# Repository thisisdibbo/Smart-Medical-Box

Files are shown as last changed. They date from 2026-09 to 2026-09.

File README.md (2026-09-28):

<p align="center">
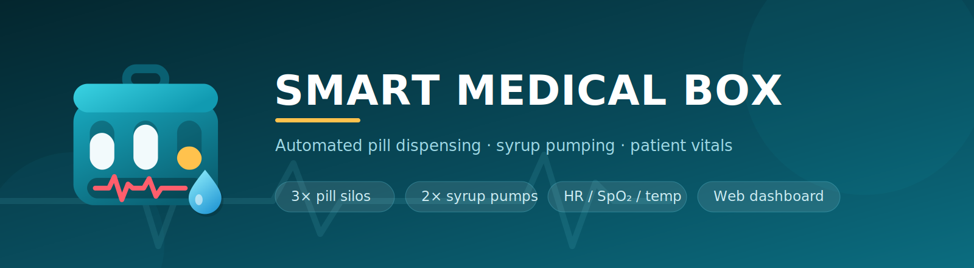
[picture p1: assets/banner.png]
Smart Medical Box
  
</p>

<p align="center">
  
  
  
  
  
</p>

A desk-sized medicine cabinet that dispenses the right pills at the right time, pumps a
measured dose of syrup after them, and reads the patient's vitals while it does it.

Three motorised silos drop one tablet each into a shared tray. A piezo disc under the tray
listens for the drop, so the box counts pills it has actually delivered rather than pills it
*thinks* it delivered. Two peristaltic pumps then run for a configurable duration. Everything
is driven by a schedule you set from a browser — morning, day and night can each have their
own silo order, pump order and dose length.

A second ESP32 handles the patient side: heart rate, SpO₂, body temperature and the water
tank level, shown live on a 3.5" TFT and pushed over Wi-Fi to the main controller so the web
dashboard sees them too.

---

## The build

| Assembled | Inside | On the bench |
|:--:|:--:|:--:|
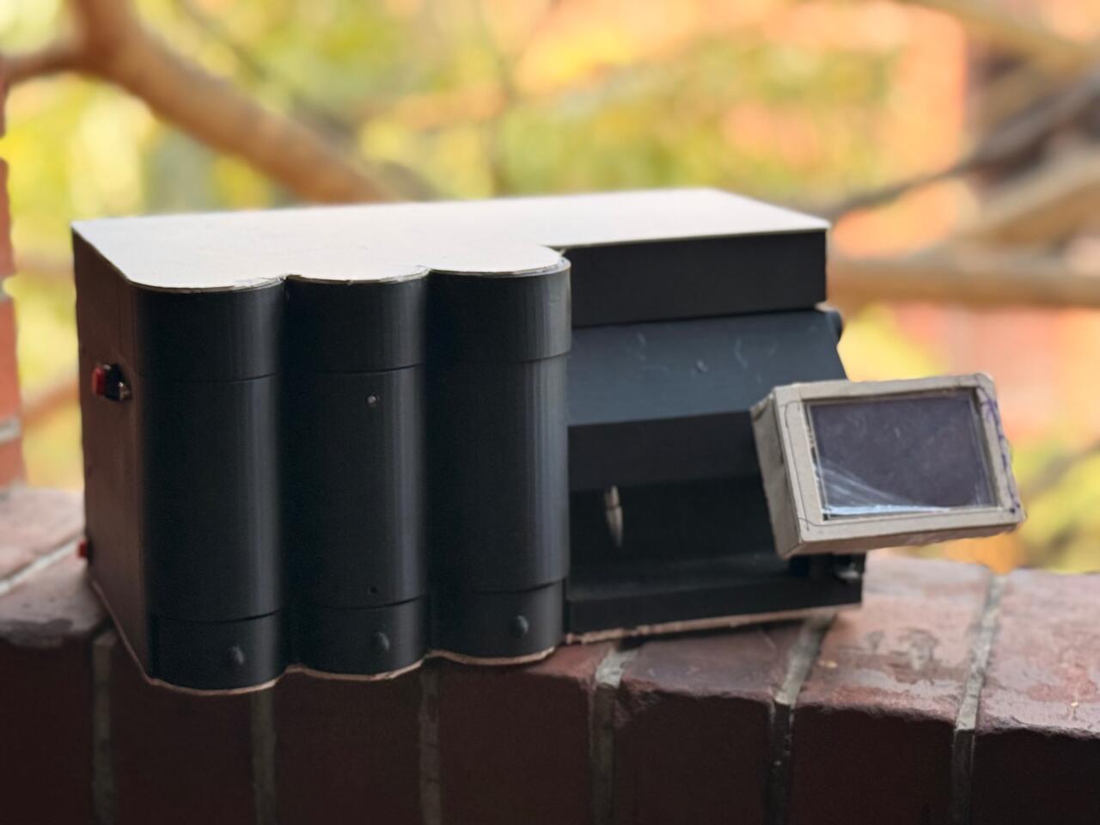
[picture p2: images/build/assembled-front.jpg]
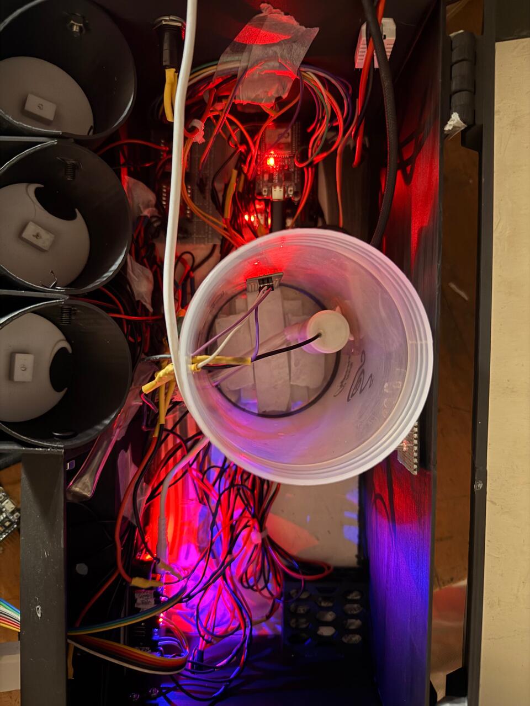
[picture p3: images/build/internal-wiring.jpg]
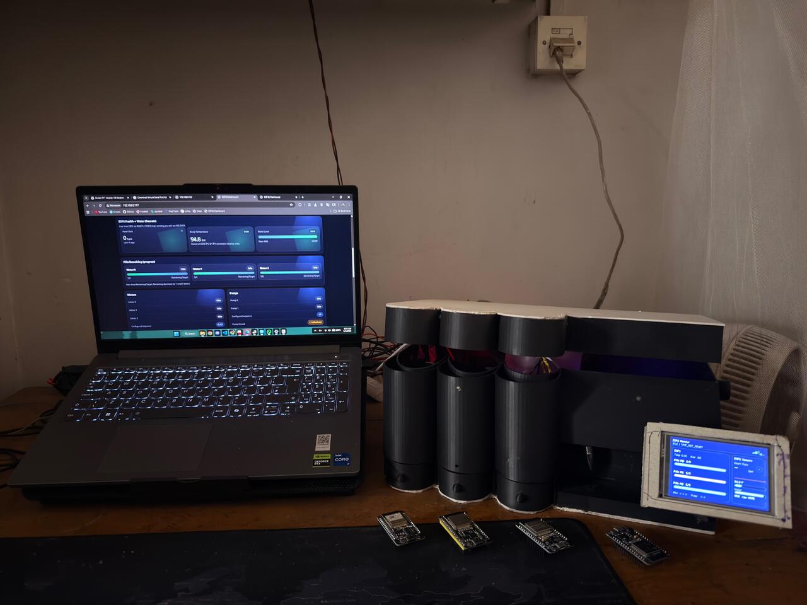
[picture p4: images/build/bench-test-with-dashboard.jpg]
|  |  |  |
| Three pill silos, hinged lid, TFT on a swing-out arm | Silos, water reservoir, drivers and the UV strip | Dashboard in the browser, TFT mirroring it |

### The dashboard

Served straight from the controller's flash — one HTML page, no app, no cloud, no account.
Open the box's address on any device on the same network.

<p align="center">
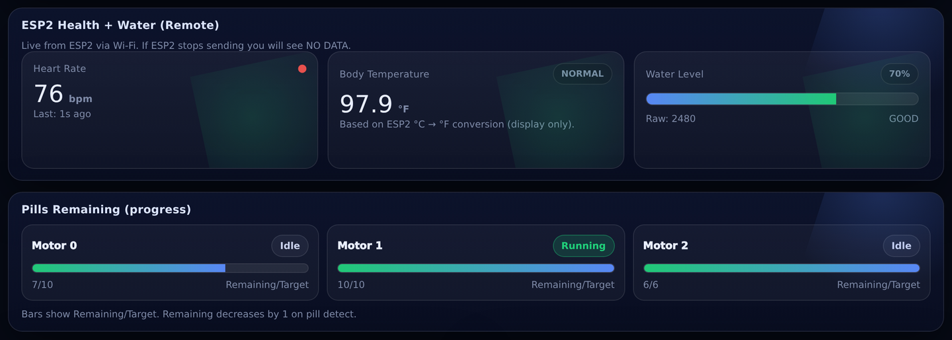
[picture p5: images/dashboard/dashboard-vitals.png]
Live vitals and pill counters
  
</p>

---

## What it does

**Dispensing**

- 3 independent pill silos, each on its own gear motor and rotating disc
- One pill per rotation; the disc pocket only ever holds a single tablet
- Piezo-disc drop detection — the motor stops the moment a pill is heard, not after a fixed time
- Per-silo pill counters that survive a power cut (stored in NVS)
- The sequence skips any silo whose counter has reached zero

**Liquid**

- 2 pumps, each with short / medium / long dose presets (1.0–5.0 s)
- Pumps run only after every scheduled silo has delivered
- Analog water-level probe with a smoothed percentage readout

**Patient monitoring**

- MAX30102 for heart rate and SpO₂, with finger-presence detection so it doesn't report noise
- I²C body-temperature sensor, clamped to a plausible 34–41 °C window
- DHT22 for cabinet temperature and humidity
- Live 3.5" TFT panel with a pulse waveform, thermometer bar and tank gauge

**Control**

- Built-in web dashboard on the controller — no app, no cloud, no account
- Three schedule windows (morning / day / night), each with its own silo and pump programme
- NTP clock so the windows follow real local time
- Physical start button, plus a latching emergency switch that cuts every output and sirens
- Four status LEDs: sequence started, sequence done, pump started, pump done

---

## How it works

The controller runs a four-state machine. One press of the start button (or `GET /startSequence`)
walks it all the way through:

```
        ┌──────┐   button / web    ┌────────────┐
        │ IDLE │ ────────────────► │ RUN_MOTOR  │ ◄──────────────┐
        └──────┘                   └─────┬──────┘                │
            ▲                            │ piezo > 400           │ next silo
            │                            ▼                       │ in the sequence
            │                    ┌─────────────────┐             │
            │                    │ WAIT_AFTER_PILL │ ────────────┘
            │                    └────────┬────────┘
            │                             │ all silos done
            │                             ▼
            │   last pump finished  ┌──────────┐
            └────────────────────── │ RUN_PUMP │
                                    └──────────┘
```

At the moment the button is pressed the firmware looks at the clock, picks whichever schedule
window is active, and copies that window's silo order, pump order and dose lengths into the
runtime. If no window is active it falls back to the saved defaults. That is why the same
button gives you two tablets in the morning and one at night without you touching anything.

The emergency switch is checked on every loop iteration, ahead of the state machine — it drops
the state back to `IDLE`, kills all motors and pumps, and toggles the buzzer every 200 ms for
as long as it is held.

---

## System architecture

The two boards are **not** wired to each other. They talk over Wi-Fi on the local network:

```
   ESP32 #2  (sensors + TFT)                    ESP32 #1  (controller)
   ─────────────────────────                    ─────────────────────
   MAX30102   ──┐                               3 × gear motor + driver
   Temp 0x7F  ──┼─ I²C                          2 × pump relay
   Water probe ─┘                               Piezo disc, DHT22
        │                                       Button, emergency, buzzer, LEDs
        │  GET /ingest?bpm=&body=&water=   ───►         │
        │           every 1.5 s                         │
        │                                               ▼
        │  GET /status  ◄───────────────────────  WebServer :80
        │           every 1 s, JSON                  + NVS + NTP
        ▼                                               │
   3.5" TFT 480×320                                     ▼
                                                  Browser dashboard
```

ESP32 #2 pushes its readings to `/ingest` and polls `/status` for everything the controller
knows, so the TFT and the browser always show the same numbers. If the controller drops off the
network, the TFT falls back to showing `ESP1 OFFLINE` and keeps displaying its own local sensors.

---

## Circuit

<p align="center">
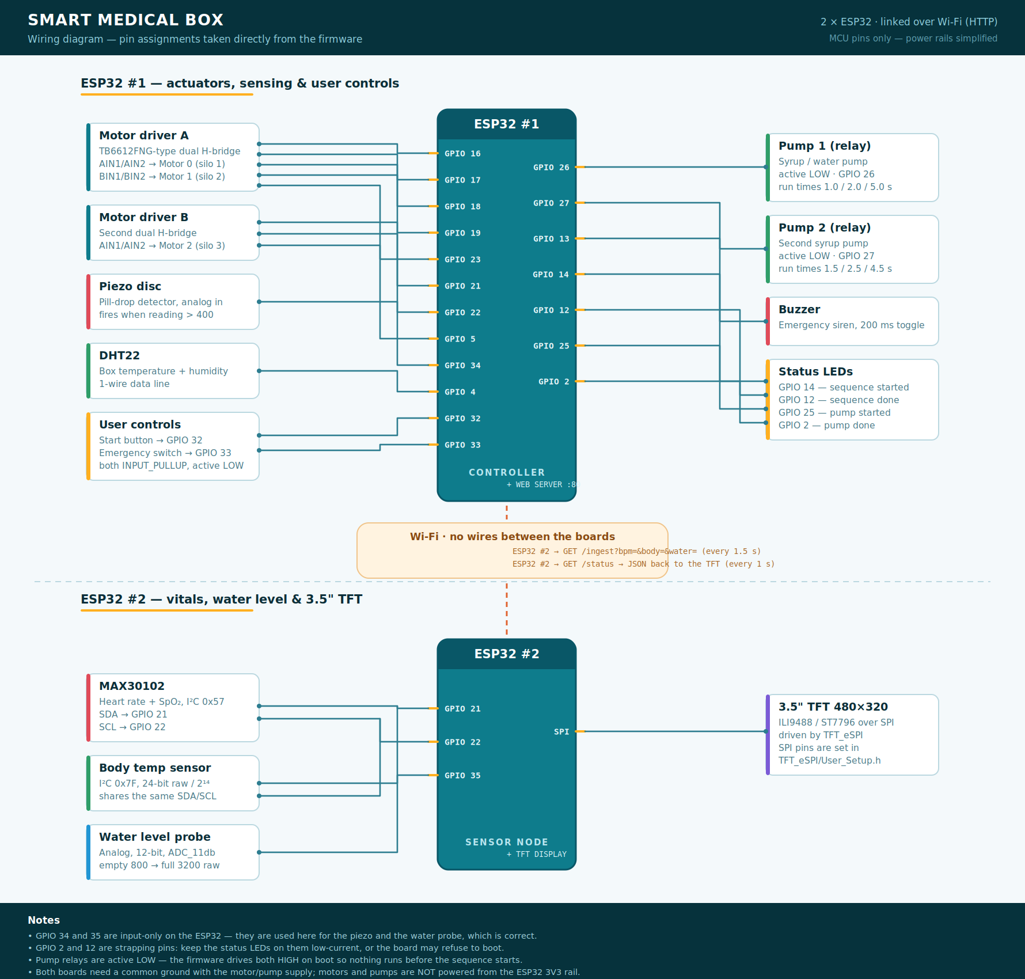
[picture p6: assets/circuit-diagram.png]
Smart Medical Box wiring diagram
  
</p>

> Vector version: [`assets/circuit-diagram.svg`](assets/circuit-diagram.svg)

### ESP32 #1 — controller

| GPIO | Direction | Connected to |
|:----:|:---:|---|
| 16 / 17 | out | Motor driver A — AIN1 / AIN2 → **Motor 0** (silo 1) |
| 18 / 19 | out | Motor driver A — BIN1 / BIN2 → **Motor 1** (silo 2) |
| 21 / 22 | out | Motor driver B — AIN1 / AIN2 → **Motor 2** (silo 3) |
| 23 | out | Driver A `STBY` (held HIGH) |
| 5  | out | Driver B `STBY` (held HIGH) |
| 34 | analog in | Piezo disc — pill-drop detector, fires above **400** |
| 26 | out | Pump 1 relay — **active LOW** |
| 27 | out | Pump 2 relay — **active LOW** |
| 32 | in, pull-up | Start button (active LOW) |
| 33 | in, pull-up | Emergency switch (active LOW) |
| 13 | out | Buzzer |
| 14 | out | LED — sequence started |
| 12 | out | LED — sequence done |
| 25 | out | LED — pump started |
| 2  | out | LED — pump done |
| 4  | 1-wire | DHT22 data |

### ESP32 #2 — sensor node + display

| GPIO | Direction | Connected to |
|:----:|:---:|---|
| 21 | I²C SDA | MAX30102 (`0x57`) and temperature sensor (`0x7F`) |
| 22 | I²C SCL | same bus |
| 35 | analog in | Water-level probe, 12-bit, `ADC_11db` |
| — | SPI | 3.5" TFT — pins live in `TFT_eSPI/User_Setup.h`, not in the sketch |

Full notes, calibration constants and gotchas: [`docs/pinout.md`](docs/pinout.md)

---

## Bill of materials

| Qty | Part | Notes |
|:---:|---|---|
| 2 | ESP32 dev board (30/38-pin) | one controller, one sensor node |
| 1 | 3.5" TFT, 480×320 | ILI9488 or ST7796, SPI |
| 3 | DC gear motor | low RPM, one per silo |
| 2 | Dual H-bridge driver with `STBY` | TB6612FNG-type; 2 boards cover 3 motors |
| 2 | Pump + relay module | active-LOW relay board |
| 1 | Piezo disc | drop sensor under the tray |
| 1 | MAX30102 | heart rate and SpO₂ |
| 1 | I²C temperature sensor `0x7F` | body temperature |
| 1 | DHT22 | cabinet temperature and humidity |
| 1 | Water-level probe | analog |
| 1 | Buzzer | emergency siren |
| 4 | LED + resistor | status indicators |
| 1 | Push button | start |
| 1 | Latching switch | emergency stop |
| — | 5 V / 12 V supply | for motors and pumps, **common ground with both ESP32s** |
| — | 3D-printed enclosure | see below |

---

## 3D-printed parts

Seven STL files in [`hardware/3d/`](hardware/3d). Everything prints flat-ish; the chassis is the
only part that needs a large bed.

| Part | File | Bounding box (mm) | Qty |
|---|---|:---:|:---:|
| Main chassis | `main-chassis.stl` | 231 × 354 × 143 | 1 |
| Top lid / cover | `lid-top-cover.stl` | 231 × 247 × 46 | 1 |
| Pill silo tube | `pill-silo-tube.stl` | 59 × 59 × 61 | 3 |
| Silo base hopper | `silo-base-hopper.stl` | 59 × 73 × 30 | 3 |
| Dispenser disc | `dispenser-disc.stl` | 54 × 53 × 9 | 3 |
| Motor / gearbox mount | `motor-gearbox-mount.stl` | 50 × 30 × 36 | 3 |
| Catch tray | `catch-tray.stl` | 50 × 51 × 21 | 1 |

<table>
  <tr>
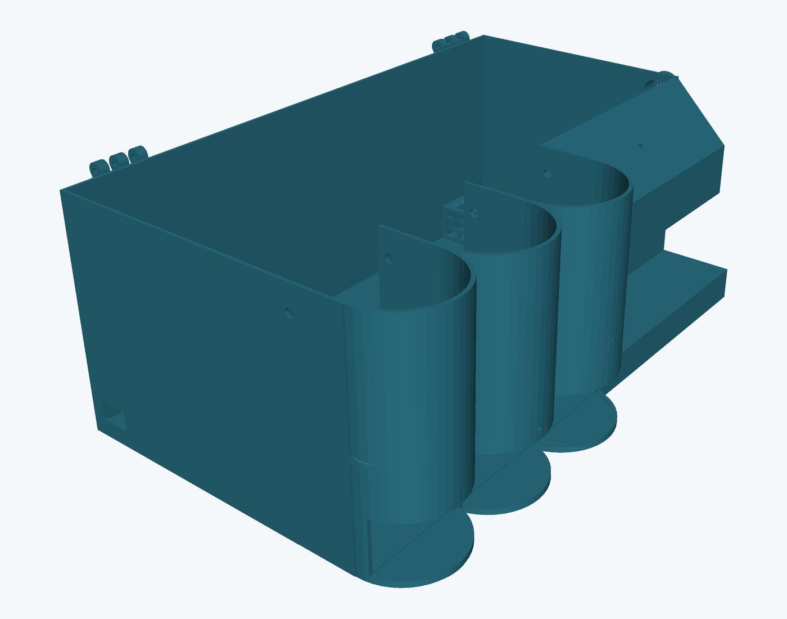
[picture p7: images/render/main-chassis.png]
    <td align="center"><br><sub>Main chassis</sub></td>
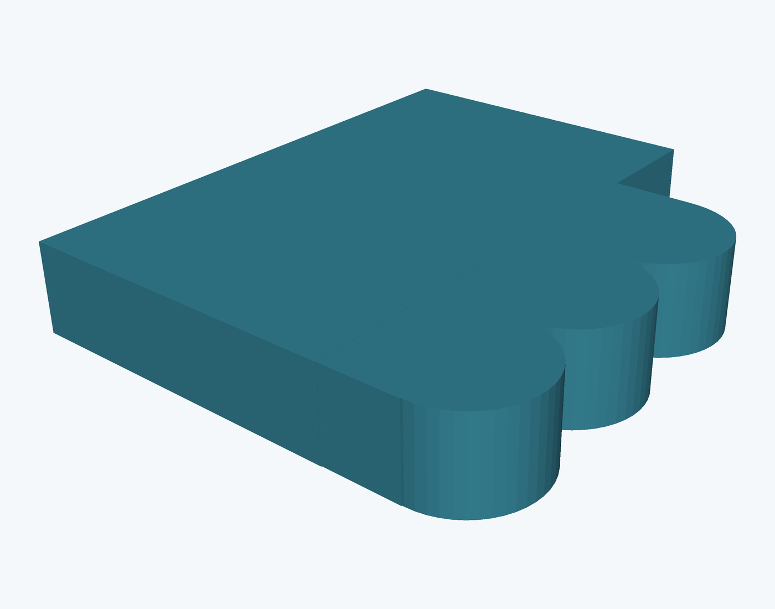
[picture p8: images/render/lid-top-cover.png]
    <td align="center"><br><sub>Top lid</sub></td>
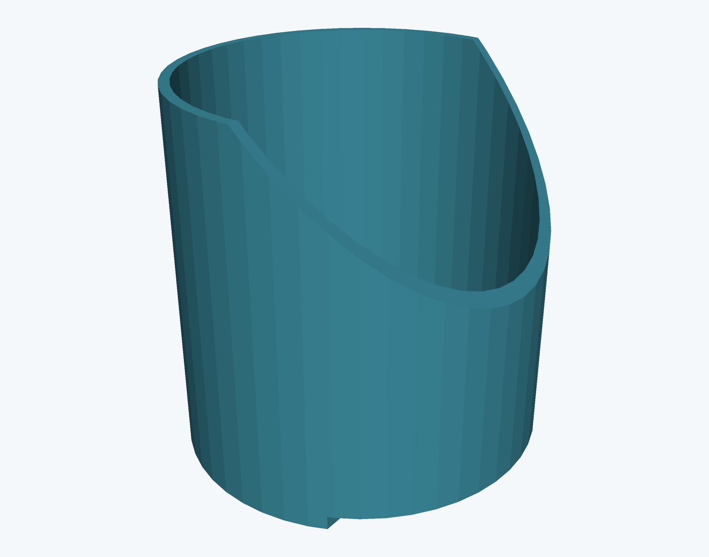
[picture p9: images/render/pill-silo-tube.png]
    <td align="center"><br><sub>Silo tube</sub></td>
  </tr>
  <tr>
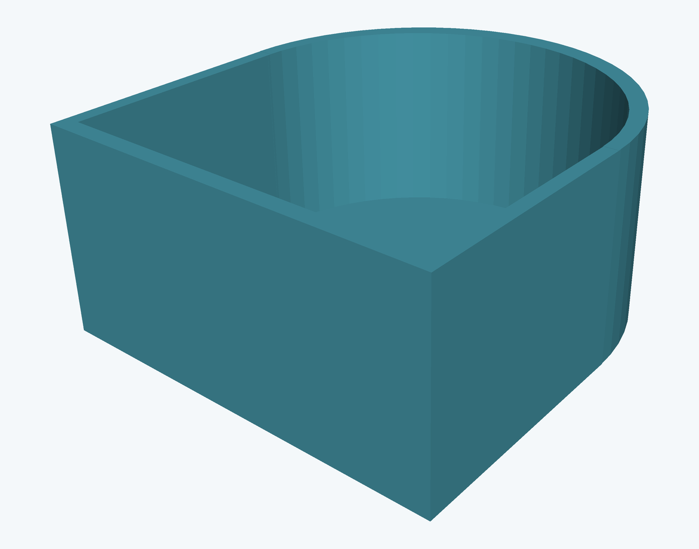
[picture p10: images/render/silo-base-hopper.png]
    <td align="center"><br><sub>Silo base hopper</sub></td>
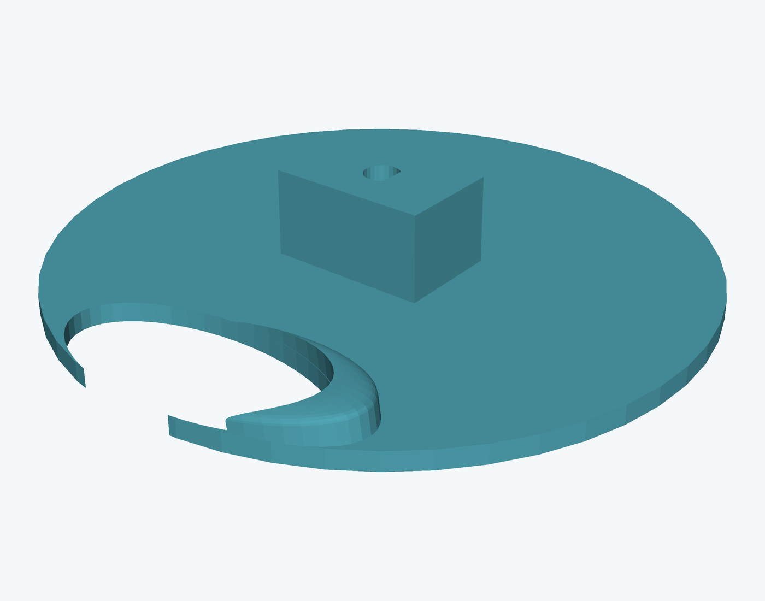
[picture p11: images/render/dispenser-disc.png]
    <td align="center"><br><sub>Dispenser disc</sub></td>
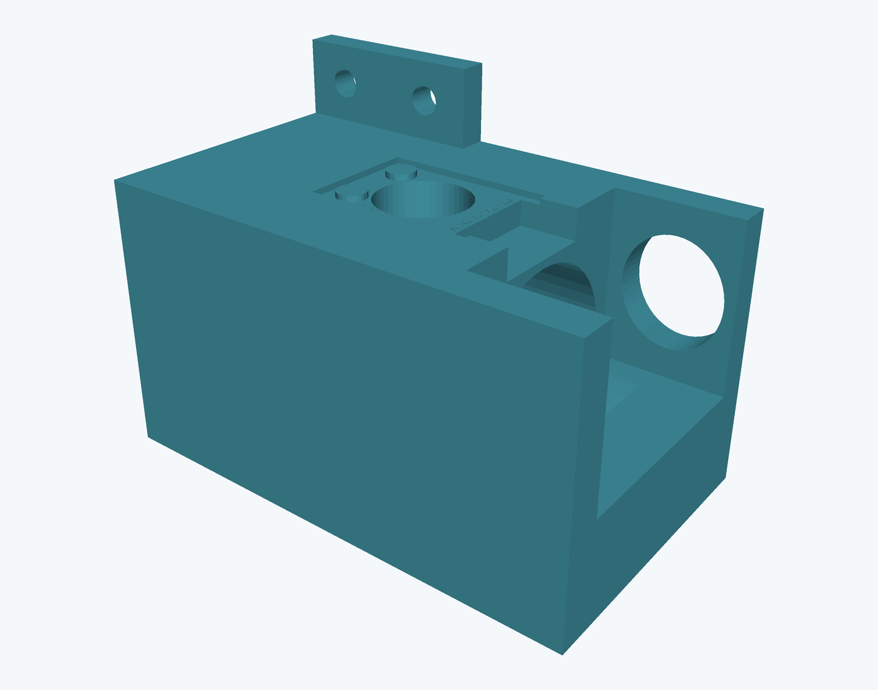
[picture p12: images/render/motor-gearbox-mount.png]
    <td align="center"><br><sub>Motor mount</sub></td>
  </tr>
</table>

CAD views of every part, including the exploded assembly, are in [`images/cad/`](images/cad).

<p align="center">
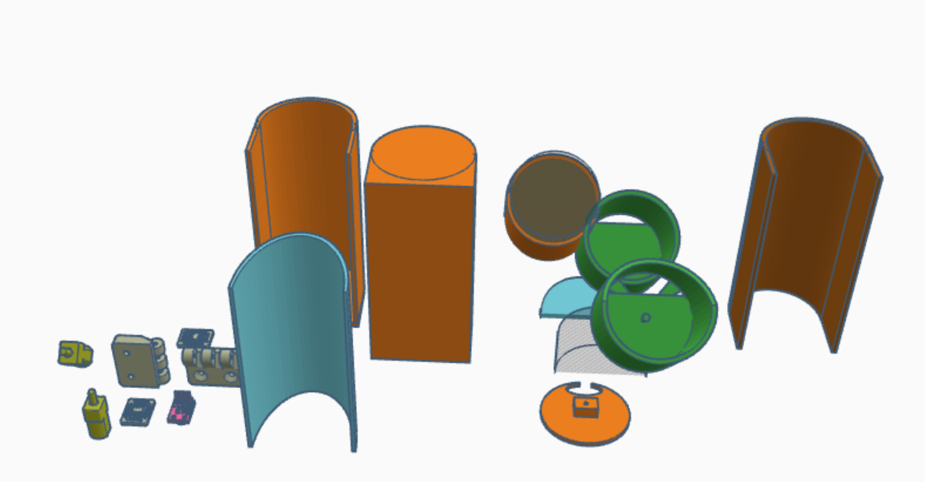
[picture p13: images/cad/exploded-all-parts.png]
  <br>
  <sub>Exploded view — all printed parts</sub>
</p>

---

## Getting started

### 1. Libraries

Install through the Arduino Library Manager:

| Sketch | Libraries |
|---|---|
| `esp1_controller` | `DHT sensor library` (Adafruit) + `Adafruit Unified Sensor` |
| `esp2_display` | `ArduinoJson`, `SparkFun MAX3010x`, `TFT_eSPI` |

Plus the **esp32** board package by Espressif (Boards Manager).

### 2. Configure Wi-Fi

Both sketches ship with placeholders. Edit them before flashing:

```cpp
const char* ssid     = "YOUR_WIFI_SSID";
const char* password = "YOUR_WIFI_PASSWORD";
```

### 3. Flash the controller first

Open [`firmware/esp1_controller`](firmware/esp1_controller), upload, then open the serial
monitor at **115200**. It prints its address:

```
WiFi Connected. IP: 192.168.0.101
```

### 4. Point the sensor node at it

In [`firmware/esp2_display`](firmware/esp2_display), set that address:

```cpp
const char* ESP1_IP = "192.168.0.101";
```

Configure `TFT_eSPI` for your panel by editing `User_Setup.h` in the library folder — driver,
SPI pins and `TFT_WIDTH 320` / `TFT_HEIGHT 480`. Then upload.

### 5. Open the dashboard

Browse to the controller's address. Set the pill counts, pick the silo and pump order, tune the
schedule windows, and press **Start** — or just press the physical button on the box.

---

## Web dashboard & HTTP API

Everything the dashboard does is a plain `GET`, so you can drive the box from `curl`, a
smart-home hub, or anything else on the network.

**Schedules** — three windows, each with its own silo order, pump order and dose presets:

<p align="center">
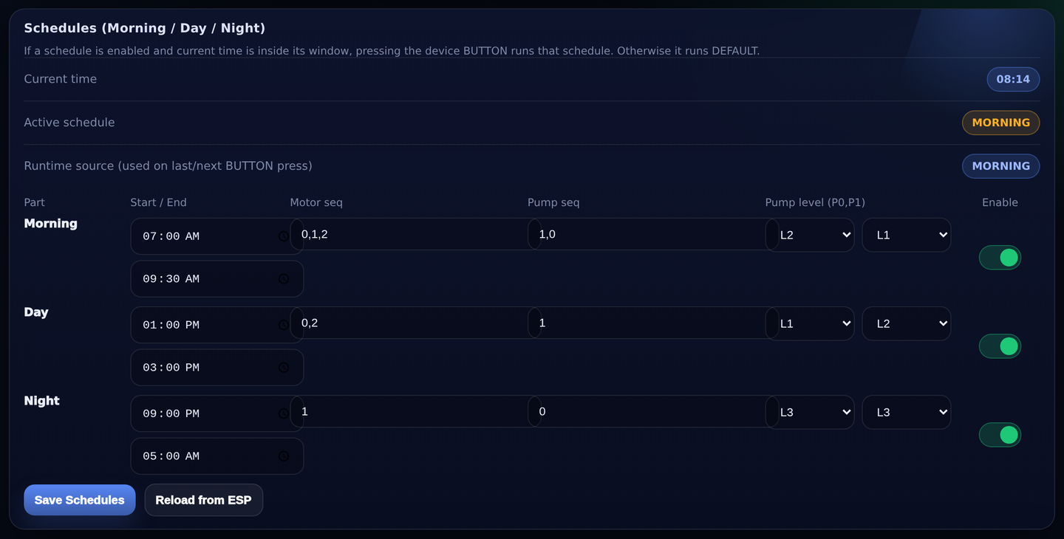
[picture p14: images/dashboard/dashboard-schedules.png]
Schedule editor
  
</p>

**Live state** — what is running right now, the configured sequences, cabinet climate and the
pill targets:

<p align="center">
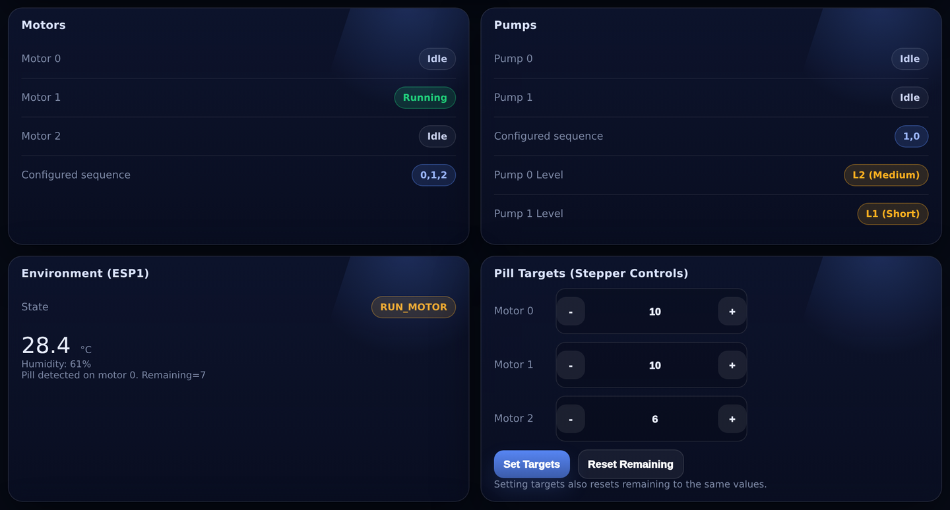
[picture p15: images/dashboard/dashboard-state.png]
Motors, pumps, environment and pill targets
  
</p>

**Sequence builder** — tap to append, drag to reorder, or type the CSV directly:

<p align="center">
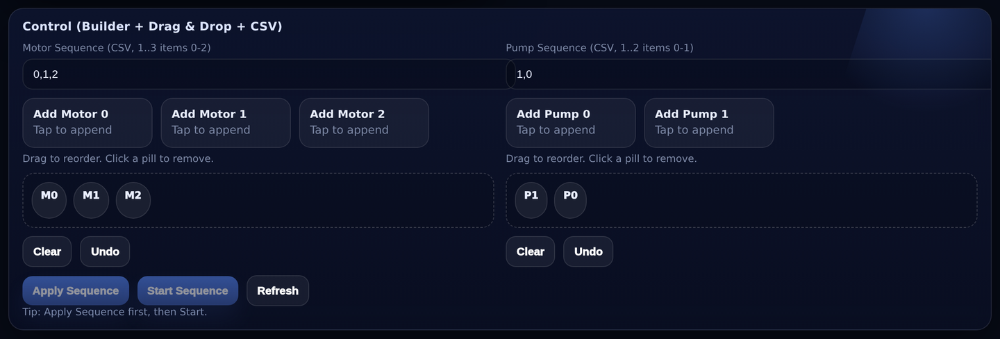
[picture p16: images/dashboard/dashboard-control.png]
Sequence builder
  
</p>

> The whole page in one shot: [`images/dashboard/dashboard-full.png`](images/dashboard/dashboard-full.png)

| Endpoint | Query parameters | Does |
|---|---|---|
| `/` | — | The dashboard page |
| `/status` | — | Full JSON state: motors, pumps, pills, DHT, sequence state, clock, remote sensors |
| `/startSequence` | — | Starts a run. `409` if one is already going |
| `/setSequence` | `motors=0,1,2` `pumps=1,0` | Sets the default silo and pump order. Values `0–2` / `0–1`, no duplicates |
| `/setPills` | `m0=` `m1=` `m2=` | Sets target **and** remaining counts per silo |
| `/resetPills` | — | Refills remaining back up to target |
| `/setPumpLevels` | `p0=` `p1=` | Dose preset per pump: `0` short, `1` medium, `2` long |
| `/getParts` | — | Returns all three schedule windows as JSON |
| `/setParts` | see below | Writes all three windows at once |
| `/ingest` | `bpm=` `body=` `water=` `ir=` | Used by ESP32 #2 to push its readings |

`/setParts` takes seven parameters per window, prefixed `m_` (morning), `d_` (day), `n_` (night):

```
m_en=1  m_s=360  m_e=600  m_m=0,1,2  m_p=1,0  m_l0=1  m_l1=0
        └ minutes past midnight ┘    └ silos ┘ └pumps┘ └ dose presets ┘
```

Anything that changes configuration is refused with `409` while a sequence is running, and every
accepted change is written to NVS immediately.

Worked examples: [`docs/api.md`](docs/api.md)

---

## Schedules

Three windows, each independently enabled, each with its own programme. Defaults:

| Window | Time | Silos | Pumps | Dose presets |
|---|---|---|---|---|
| Morning | 06:00 – 10:00 | 0, 1, 2 | 1, 0 | medium / short |
| Day | 10:00 – 18:00 | 0, 2 | 1 | short / medium |
| Night | 18:00 – 06:00 | 1 | 0 | long / long |

All three ship **disabled** so the box uses the saved defaults until you turn them on. Windows
may wrap past midnight — the night window above is handled correctly.

Pump run times, in milliseconds:

| | short | medium | long |
|---|:---:|:---:|:---:|
| Pump 0 | 1000 | 2000 | 5000 |
| Pump 1 | 1500 | 2500 | 4500 |

---

## Calibration

Three constants are worth tuning for your build — all of them are at the top of the sketches.

**Piezo threshold** (`esp1_controller`, `PIEZO_THRESHOLD 400`)
Print the raw `analogRead(PIEZO)` while dropping a tablet. Set the threshold roughly halfway
between the resting value and the peak. Too low and motor vibration registers as a pill; too
high and small tablets are missed and the motor keeps turning.

**Water probe** (`esp2_display`, `WATER_EMPTY_RAW 800` / `WATER_FULL_RAW 3200`)
Read the raw ADC with the tank empty and again full, and put those two numbers in. The reading
is smoothed 70/30 against the previous sample, so it settles over a few seconds instead of
jumping.

**Body temperature offset** (`esp2_display`, `BODY_TEMP_OFFSET_C 1.5f`)
A skin-contact sensor reads below core temperature. Compare against a clinical thermometer and
adjust. The result is clamped to 34–41 °C.

---

## Repository layout

```
Smart-Medical-Box/
├── firmware/
│   ├── esp1_controller/        main controller — motors, pumps, web server, schedules
│   ├── esp2_display/           sensor node — MAX30102, temperature, water, TFT
│   └── archive/                earlier iterations, kept for reference
│       ├── esp1_controller_early/
│       └── vitals_oled_test/   MAX30102 + SH1106 OLED bring-up sketch
├── hardware/
│   └── 3d/                     7 STL files for the printed enclosure
├── docs/
│   ├── pinout.md               complete pin map, constants and electrical notes
│   └── api.md                  HTTP API with curl examples
├── images/
│   ├── build/                  photos of the finished box
│   ├── dashboard/              screenshots of the web dashboard
│   ├── cad/                    CAD views of every part
│   └── render/                 renders straight from the STLs
├── assets/                     logo, banner, wiring diagram (PNG + SVG)
└── README.md
```

---

## Roadmap

From the original design notes — what is in, and what is still to come.

- [x] Water / syrup level indicator
- [x] Tablet drop detection
- [x] Emergency stop with siren
- [x] Patient vitals — HR, SpO₂, body temperature
- [x] Scheduled dosing windows
- [ ] RTC module, so the clock survives a Wi-Fi outage instead of relying on NTP
- [ ] SD card logging of every dose delivered
- [ ] Silica gel slot with a humidity-triggered reminder
- [ ] UV sterilisation cycle for the tray
- [ ] Syrup mixing before the pump runs
- [ ] GSR skin sensor
- [ ] Magnetic door sensor to log when the box is opened

---

## Safety

This is a student hardware project, not a medical device. It has no redundancy, no fail-safe
dosing lockout and no regulatory approval. Do not use it to manage medication anybody actually
depends on.

---

## Author

**Md. Mahin Rahman**
GitHub: [@thisisdibbo](https://github.com/thisisdibbo)
Email: mr.d2003feb@gmail.com

## License

MIT — see [LICENSE](LICENSE).

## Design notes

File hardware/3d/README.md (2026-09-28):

# 3D-printed parts

Seven STL files make up the enclosure. Dimensions are the raw bounding boxes from the meshes, in
millimetres, so allow for your printer's tolerance on the fits.

| Part | File | Bounding box | Triangles | Qty |
|---|---|:---:|:---:|:---:|
| Main chassis | `main-chassis.stl` | 231 × 354 × 143 | 9,746 | 1 |
| Top lid / cover | `lid-top-cover.stl` | 231 × 247 × 46 | 3,998 | 1 |
| Pill silo tube | `pill-silo-tube.stl` | 59 × 59 × 61 | 624 | 3 |
| Silo base hopper | `silo-base-hopper.stl` | 59 × 73 × 30 | 2,104 | 3 |
| Dispenser disc | `dispenser-disc.stl` | 54 × 53 × 9 | 1,204 | 3 |
| Motor / gearbox mount | `motor-gearbox-mount.stl` | 50 × 30 × 36 | 3,236 | 3 |
| Catch tray | `catch-tray.stl` | 50 × 51 × 21 | 2,310 | 1 |

Renders of each part: [`../../images/render/`](../../images/render)
CAD views and the exploded assembly: [`../../images/cad/`](../../images/cad)

## Printing

| | |
|---|---|
| Material | PLA is fine; PETG if the box will sit anywhere warm |
| Layer height | 0.2 mm, or 0.15 mm for the dispenser disc |
| Walls | 3 perimeters — the silo tubes take side load from the tablets |
| Infill | 20 % for structure, 40 %+ for the dispenser disc and motor mount |
| Supports | Only the main chassis needs them, under the silo wells |

The **main chassis** is 231 × 354 mm, which is larger than a 220 × 220 bed. Either print it on a
300 mm-class printer, or split it in your slicer and join the halves — the built unit in the
photos uses a split chassis with the seam running between the silo bank and the electronics bay.

## Fit notes

- The **dispenser disc** pocket is sized for one standard tablet. Print a test disc first and
  check your actual tablets drop cleanly and only one at a time — this is the part worth
  iterating on.
- The **motor mount** has a bracket with two screw holes and a bore for the gearbox shaft. Check
  the bore against your motor before committing to three copies.
- The **silo tube** sits inside the chassis well and drops onto the base hopper; the angled cut
  at the top is the refill opening.
- The **catch tray** takes the piezo disc underneath — glue the piezo flat to the underside of
  the floor so a falling tablet couples into it properly. A loose piezo gives unreliable
  detection and is the most common reason the motor keeps running past a pill.

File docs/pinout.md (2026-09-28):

# Pinout and electrical notes

Everything here is read straight from the firmware. If you change a pin in a sketch, change it
here too.

---

## ESP32 #1 — controller

`firmware/esp1_controller/esp1_controller.ino`

### Motors

Three DC gear motors across two dual H-bridge drivers. The drivers have a `STBY` line, which
points at TB6612FNG-type boards — an L298N has no standby pin and would need the code changed.

| Signal | GPIO | Driver pin | Drives |
|---|:----:|---|---|
| `M1_IN1` | 16 | A-IN1, driver A | Motor 0 — silo 1 |
| `M1_IN2` | 17 | A-IN2, driver A | Motor 0 — silo 1 |
| `M2_IN1` | 18 | B-IN1, driver A | Motor 1 — silo 2 |
| `M2_IN2` | 19 | B-IN2, driver A | Motor 1 — silo 2 |
| `M3_IN1` | 21 | A-IN1, driver B | Motor 2 — silo 3 |
| `M3_IN2` | 22 | A-IN2, driver B | Motor 2 — silo 3 |
| `STBY1`  | 23 | STBY, driver A | held HIGH in `setup()` |
| `STBY2`  | 5  | STBY, driver B | held HIGH in `setup()` |

Motors 1 and 2 are driven in reverse (`IN1` LOW, `IN2` HIGH) in `driveMotorForward()` because
their gearboxes are mounted mirrored. Motor 0 runs the other way round. If you rebuild the
mechanism, that function is the single place to fix rotation direction.

### Pumps

| Signal | GPIO | Notes |
|---|:----:|---|
| `PUMP1_PIN` | 26 | **Active LOW** — driven HIGH in `setup()` and whenever idle |
| `PUMP2_PIN` | 27 | same |

Run times, in milliseconds, indexed by the dose preset (0 short, 1 medium, 2 long):

```cpp
unsigned long pumpRunTime[2][3] = {
  {1000, 2000, 5000},   // pump 0
  {1500, 2500, 4500}    // pump 1
};
```

### Sensing and controls

| Signal | GPIO | Mode | Notes |
|---|:----:|---|---|
| `PIEZO` | 34 | analog in | Pill-drop detector. `PIEZO_THRESHOLD 400` |
| `DHTPIN` | 4 | 1-wire | DHT22, cabinet temperature and humidity |
| `BUTTON` | 32 | `INPUT_PULLUP` | Start. Active LOW, edge-detected |
| `EMERGENCY_SWITCH` | 33 | `INPUT_PULLUP` | Active LOW. Checked before the state machine |
| `BUZZER_PIN` | 13 | out | Siren, toggled every 200 ms while emergency is held |

### Status LEDs

| Signal | GPIO | Lights when |
|---|:----:|---|
| `LED_SEQ_START` | 14 | A dispensing sequence is running |
| `LED_SEQ_DONE` | 12 | All silos have delivered — clears after 10 s |
| `LED_PUMP_START` | 25 | A pump is running |
| `LED_PUMP_DONE` | 2 | Pumping finished — clears after 10 s |

---

## ESP32 #2 — sensor node and display

`firmware/esp2_display/esp2_display.ino`

| Signal | GPIO | Notes |
|---|:----:|---|
| I²C `SDA` | 21 | `Wire.begin(21, 22)` |
| I²C `SCL` | 22 | |
| `WATER_ADC_PIN` | 35 | 12-bit, `ADC_11db` |
| TFT | SPI | Set in `TFT_eSPI/User_Setup.h`, not in the sketch |

### I²C devices

| Address | Device | Reads |
|:---:|---|---|
| `0x57` | MAX30102 | IR + red → heart rate and SpO₂ |
| `0x7F` | Temperature sensor | 24-bit signed, command register `0x30`, data from `0x10` |

The temperature sensor is read as a 24-bit two's-complement value divided by 2¹⁴ (16384.0), with
`BODY_TEMP_OFFSET_C 1.5f` added and the result clamped to 34–41 °C.

### MAX30102 configuration

```cpp
particleSensor.setup(10, 4, 2, 100, 411, 4096);
//                   │   │  │   │    │    └ ADC range
//                   │   │  │   │    └ pulse width
//                   │   │  │   └ sample rate
//                   │   │  └ LED mode (red + IR)
//                   │   └ sample averaging
//                   └ LED brightness
```

Finger presence is a moving comparison: the IR baseline is captured over 50 samples at boot, and
a finger is considered present when the average of the next 100 samples exceeds that baseline by
`IR_THRESHOLD` (8000). BPM is only accepted inside 55–110.

### Water level

```cpp
WATER_EMPTY_RAW = 800    // raw ADC with the tank empty
WATER_FULL_RAW  = 3200   // raw ADC with the tank full
```

Linear map to 0–100 %, then smoothed 70 % previous / 30 % new each loop.

---

## Electrical notes

**Input-only pins.** GPIO 34 and 35 have no output driver and no internal pull-up or pull-down.
Both are used as analog inputs here, which is the correct use. Do not try to drive anything from
them.

**Strapping pins.** GPIO 2, 5 and 12 are read at boot to decide the boot mode.

- GPIO 2 drives an LED — keep it low-current and make sure nothing holds it high during reset.
- GPIO 12 (MTDI) selects flash voltage. A strong pull-up here can stop the board booting. Use a
  series resistor and a low-current LED, or move this LED to a spare pin if you see boot loops.
- GPIO 5 drives a driver `STBY` line; the driver's own input impedance is high enough that this
  is normally fine.

**ADC2 and Wi-Fi.** ADC2 pins cannot be read while Wi-Fi is active. Both analog inputs used here
(34 and 35) are on ADC1, so this project is unaffected — but keep it in mind if you add sensors.

**Power.** Motors, pumps and the ESP32s share a ground, but the motors and pumps must be fed
from their own supply, never from the ESP32's 3V3 regulator. A stall on a gear motor will brown
out the board and reset it mid-sequence. Add a bulk capacitor (470 µF+) across the motor supply
close to the drivers, and flyback protection on the pump relays if your relay board doesn't have
it already.

**Wi-Fi stability.** The controller disables power save explicitly:

```cpp
WiFi.setSleep(false);
esp_wifi_set_ps(WIFI_PS_NONE);
```

Without it the board drops off the network while idle, `/ingest` starts failing, and it looks
like the sensor node has stopped sending. The loop also calls `delay(1)` so the Wi-Fi stack gets
scheduling time.

---

## Persistence

Saved to NVS (namespace `appcfg`) and reloaded on every boot:

- default motor and pump sequences, and their lengths
- per-silo pill targets and remaining counts
- pump dose presets
- all three schedule windows

The remaining count is written the instant a pill is detected, so a power cut mid-sequence
cannot cause a double dose on the next run.

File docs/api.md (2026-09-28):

# HTTP API

The controller runs a plain `WebServer` on port 80. Every endpoint is a `GET`, including the
ones that change state, so anything that can fetch a URL can drive the box.

Replace `192.168.0.101` with whatever the controller printed on the serial monitor at boot.

---

## `GET /`

The dashboard page. Plain HTML and JavaScript served from flash — no external assets, so it
works with no internet connection.

---

## `GET /status`

Everything the controller knows, as JSON. The dashboard polls this, and so does ESP32 #2.

```bash
curl http://192.168.0.101/status
```

```jsonc
{
  "motors": [ {"status":"Idle"}, {"status":"Running"}, {"status":"Idle"} ],
  "pumps":  [ {"status":"Idle"}, {"status":"Idle"} ],
  "dht":    { "temp": 28.4, "hum": 61.0 },
  "sequence": { "motors": "0,1,2", "pumps": "1,0" },
  "pumpLevels": [1, 0],
  "pills": {
    "target":    [5, 5, 5],
    "remaining": [3, 5, 5]
  },
  "uiMsg": "Pill detected on motor 0. Remaining=3",
  "ip": "192.168.0.101",
  "seqState": "RUN_MOTOR",          // IDLE | RUN_MOTOR | WAIT_AFTER_PILL | RUN_PUMP
  "timeReady": true,                // false until NTP has synced
  "nowHHMM": "08:14",
  "activePart": "MORNING",          // MORNING | DAY | NIGHT | NONE | TIME_NOT_READY
  "runtimeSource": "MORNING",       // DEFAULT | WEB | MORNING | DAY | NIGHT
  "remote": {                       // pushed by ESP32 #2
    "ok": true,
    "ageMs": 820,                   // how stale the reading is
    "bpm": 76,
    "bodyTempC": 36.60,
    "irTempC": 36.60,
    "waterRaw": 2480,
    "waterPct": 70
  }
}
```

`remote.ageMs` is the honest one to watch — `ok` stays `true` after the first successful push,
so a sensor node that has gone offline shows as `ok: true` with a growing age. Treat anything
over a few seconds as stale.

---

## `GET /startSequence`

Starts a dispensing run, exactly as the physical button does.

```bash
curl http://192.168.0.101/startSequence
```

| Response | Meaning |
|---|---|
| `200 {"ok":true,"msg":"Sequence started"}` | Running |
| `409 {"ok":false,"msg":"Sequence already running"}` | One is already in progress |
| `400 {"ok":false,"msg":"All motors have 0 remaining pills"}` | Refill first |

Unlike the button, this does **not** re-read the schedule — it uses the current default
sequence. The button path calls `pickRuntimeForButton()` and loads the active window.

---

## `GET /setSequence`

Sets the default silo and pump order.

```bash
curl "http://192.168.0.101/setSequence?motors=0,2&pumps=1"
```

| Parameter | Values |
|---|---|
| `motors` | CSV of `0`–`2`, 1 to 3 entries, no duplicates |
| `pumps` | CSV of `0`–`1`, 1 to 2 entries, no duplicates |

Order matters — `motors=2,0,1` dispenses from silo 3 first. Saved to NVS.

---

## `GET /setPills`

Sets the target count for each silo. Remaining is set to the same value, so this is also how you
tell the box you have refilled it.

```bash
curl "http://192.168.0.101/setPills?m0=10&m1=10&m2=6"
```

All three parameters are required and must be `>= 0`.

---

## `GET /resetPills`

Puts remaining back up to target without changing the targets.

```bash
curl http://192.168.0.101/resetPills
```

---

## `GET /setPumpLevels`

Dose preset per pump.

```bash
curl "http://192.168.0.101/setPumpLevels?p0=2&p1=1"
```

| Value | Preset | Pump 0 | Pump 1 |
|:--:|---|:--:|:--:|
| `0` | short | 1000 ms | 1500 ms |
| `1` | medium | 2000 ms | 2500 ms |
| `2` | long | 5000 ms | 4500 ms |

---

## `GET /getParts`

Returns all three schedule windows.

```bash
curl http://192.168.0.101/getParts
```

```jsonc
{
  "morning": { "enabled": false, "startMin": 360, "endMin": 600,
               "motors": "0,1,2", "pumps": "1,0", "levels": [1, 0] },
  "day":     { "enabled": false, "startMin": 600, "endMin": 1080,
               "motors": "0,2",   "pumps": "1",   "levels": [0, 1] },
  "night":   { "enabled": false, "startMin": 1080, "endMin": 360,
               "motors": "1",     "pumps": "0",   "levels": [2, 2] }
}
```

Times are minutes past midnight, `0`–`1439`. A window where `startMin > endMin` wraps past
midnight, which is how the night window covers 18:00 → 06:00.

---

## `GET /setParts`

Writes all three windows in one request. Every parameter is required — there is no partial
update, so read `/getParts` first if you only want to change one thing.

| Prefix | Window |
|---|---|
| `m_` | morning |
| `d_` | day |
| `n_` | night |

| Suffix | Meaning |
|---|---|
| `_en` | `1` enabled, `0` disabled |
| `_s` | start, minutes past midnight |
| `_e` | end, minutes past midnight |
| `_m` | silo order, CSV `0`–`2` |
| `_p` | pump order, CSV `0`–`1` |
| `_l0` | pump 0 dose preset, `0`–`2` |
| `_l1` | pump 1 dose preset, `0`–`2` |

Morning 07:00–09:30 with all three silos, day disabled, night 21:00–05:00 with silo 2 only:

```bash
curl "http://192.168.0.101/setParts?\
m_en=1&m_s=420&m_e=570&m_m=0,1,2&m_p=1,0&m_l0=1&m_l1=0&\
d_en=0&d_s=600&d_e=1080&d_m=0,2&d_p=1&d_l0=0&d_l1=1&\
n_en=1&n_s=1260&n_e=300&n_m=1&n_p=0&n_l0=2&n_l1=2"
```

Errors come back as `400` with the reason: `Missing schedule args`, `Invalid start/end`,
`Invalid motor seq`, `Invalid pump seq` or `Invalid pump levels`. Nothing is written unless all
three windows validate.

---

## `GET /ingest`

Used by ESP32 #2 to push its readings. You can call it by hand to test the dashboard without the
sensor node connected.

```bash
curl "http://192.168.0.101/ingest?bpm=72&body=36.6&water=2400&ir=36.6"
```

| Parameter | Required | Meaning |
|---|:--:|---|
| `bpm` | yes | Heart rate |
| `body` | yes | Body temperature, °C |
| `water` | yes | Raw water ADC reading, not a percentage |
| `ir` | no | IR temperature, °C |

Missing any of the three required parameters returns `400`.

---

## Notes

**Configuration is locked while running.** `/setSequence`, `/setPills`, `/resetPills`,
`/setPumpLevels` and `/setParts` all return `409` unless `seqState` is `IDLE`. Poll `/status`
first if you are scripting against the box.

**No authentication.** Anything on the same network can dispense pills. Keep the box off guest
Wi-Fi, and don't port-forward it.

**Writes are immediate.** Every accepted change is committed to NVS before the response is sent,
so a power cut right after a `200` cannot lose the setting.

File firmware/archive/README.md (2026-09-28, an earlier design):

# Archive

Earlier iterations, kept because they document how the project got here. Neither is what runs on
the built unit — use [`../esp1_controller`](../esp1_controller) and
[`../esp2_display`](../esp2_display) for that.

## `esp1_controller_early/`

An earlier controller build with the same motor, pump and schedule logic but before the Wi-Fi
stability work. It has no power-save disable, no reconnect loop and no Wi-Fi event logging, so
it drops off the network after a while and `/ingest` starts failing — which reads as "the sensor
node stopped sending" even though the sensor node is fine.

Kept for the dashboard HTML, which is close to the final version and easier to read in isolation.

## `vitals_oled_test/`

The MAX30102 bring-up sketch: heart rate, SpO₂ and the `0x7F` temperature sensor on a 128×64
SH1106 OLED, with no Wi-Fi and nothing else attached. This is the quickest way to prove a
sensor board works before wiring it into the box.

Needs `Adafruit_GFX`, `Adafruit_SH110X` and `SparkFun MAX3010x`.

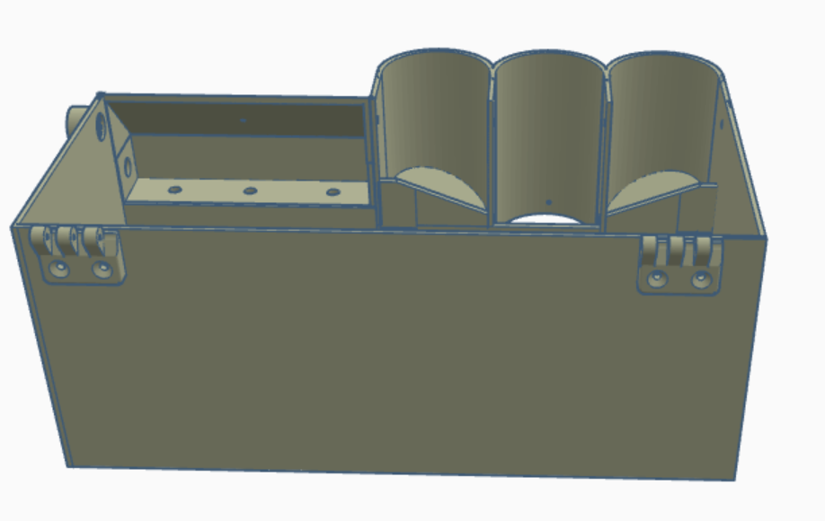
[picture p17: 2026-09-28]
images/cad/chassis-iso.png

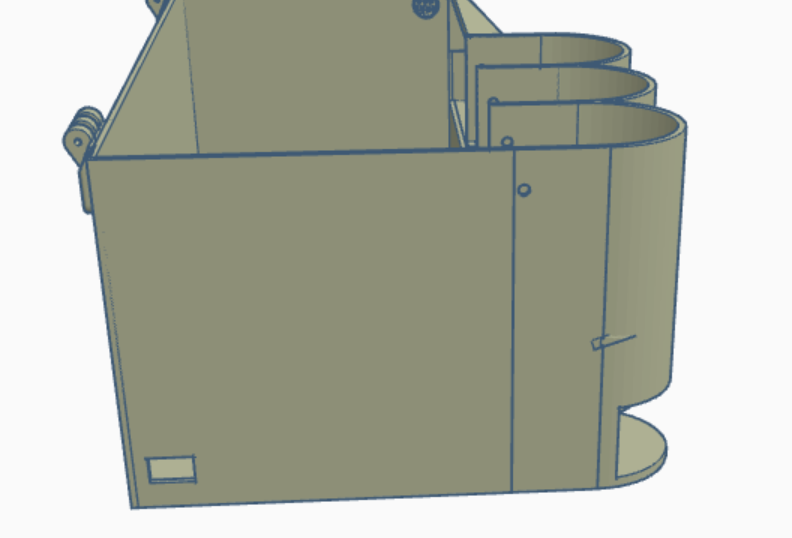
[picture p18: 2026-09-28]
images/cad/chassis-rear-quarter.png

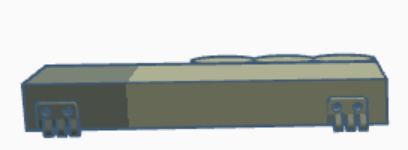
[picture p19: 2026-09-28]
images/cad/lid-front-edge.png

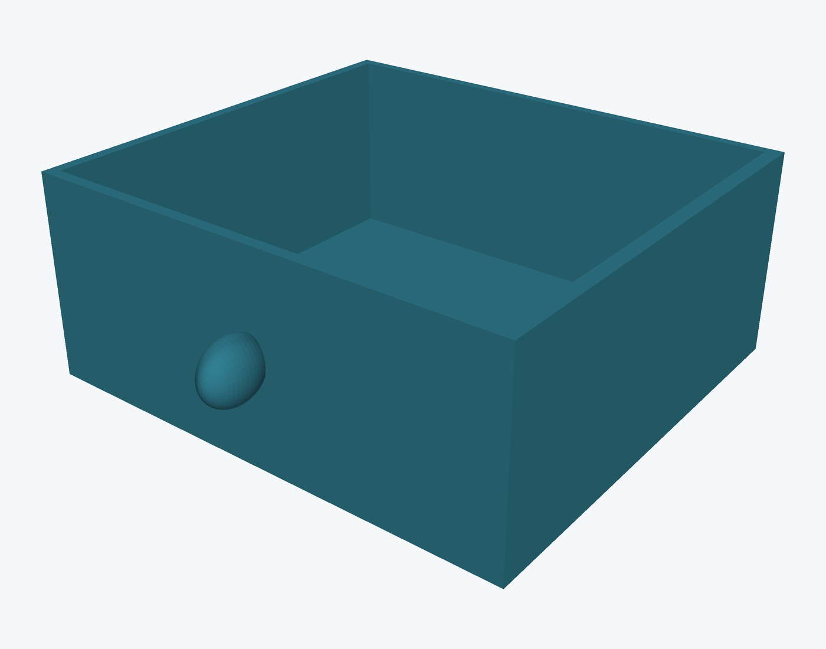
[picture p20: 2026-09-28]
images/render/catch-tray.png

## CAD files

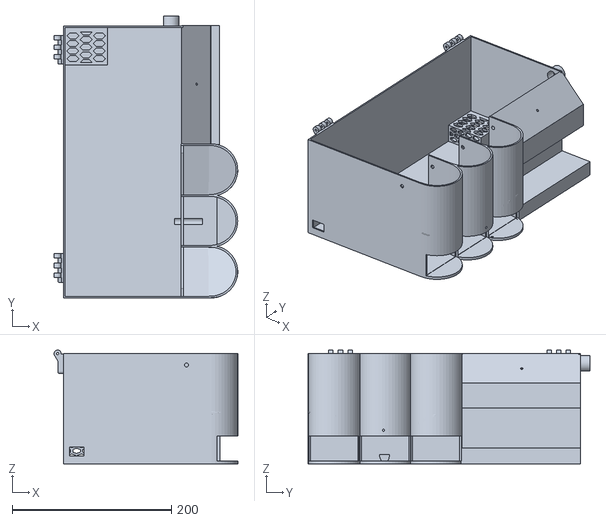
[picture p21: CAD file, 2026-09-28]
hardware/3d/main-chassis.stl
231.1 x 354.4 x 143.2

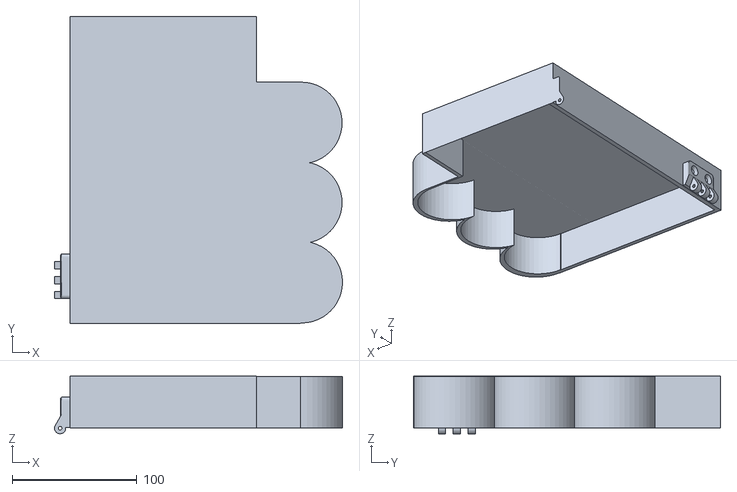
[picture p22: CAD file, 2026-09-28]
hardware/3d/lid-top-cover.stl
231.1 x 246.6 x 46.2

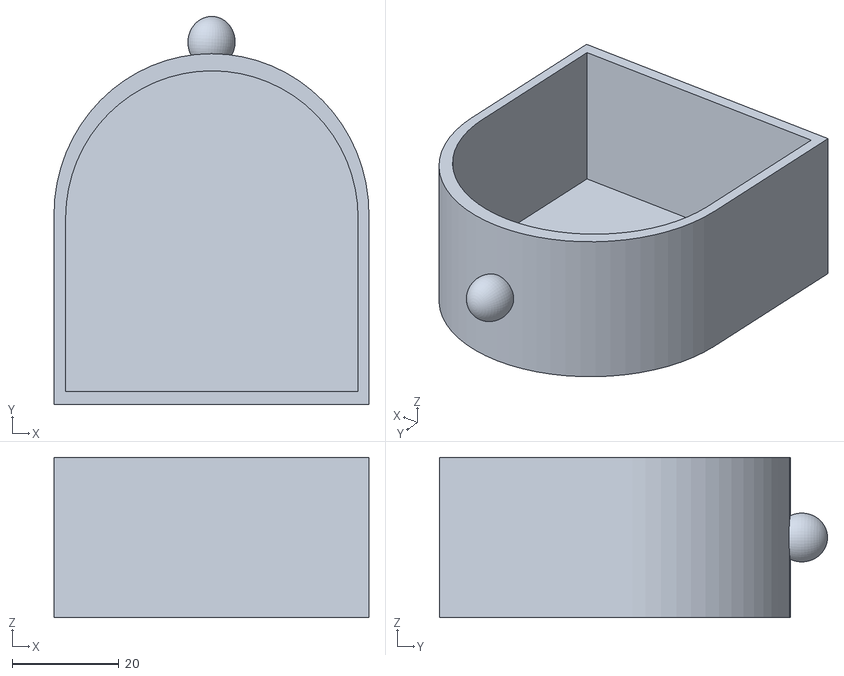
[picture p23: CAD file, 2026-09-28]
hardware/3d/silo-base-hopper.stl
59.0 x 72.7 x 30.0

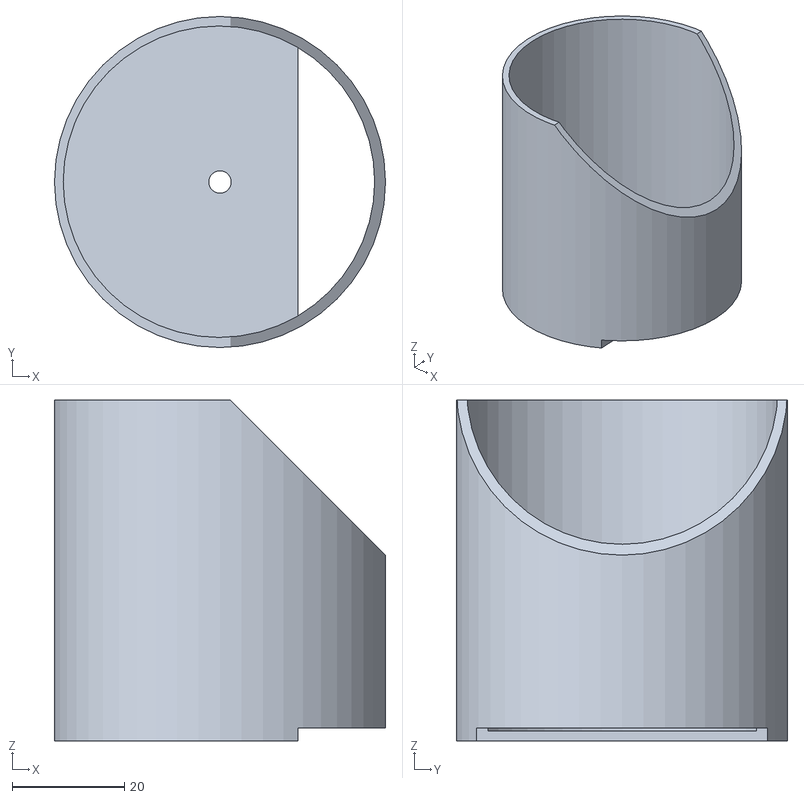
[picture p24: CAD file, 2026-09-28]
hardware/3d/pill-silo-tube.stl
59.1 x 59.1 x 60.9

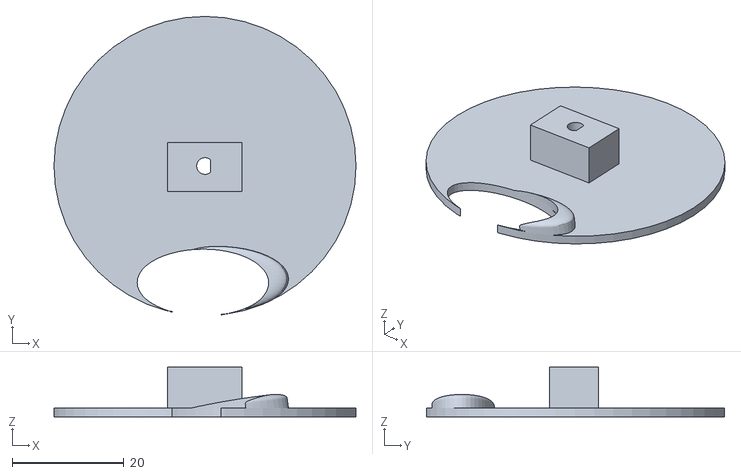
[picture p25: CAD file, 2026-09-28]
hardware/3d/dispenser-disc.stl
54.1 x 53.4 x 8.90

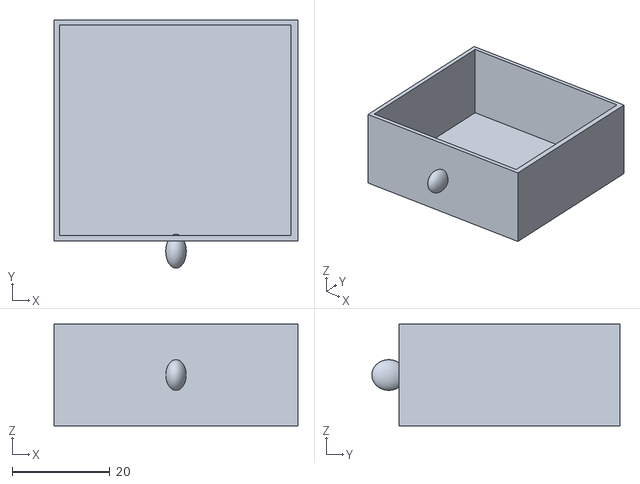
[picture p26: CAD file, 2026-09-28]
hardware/3d/catch-tray.stl
49.9 x 50.8 x 20.8

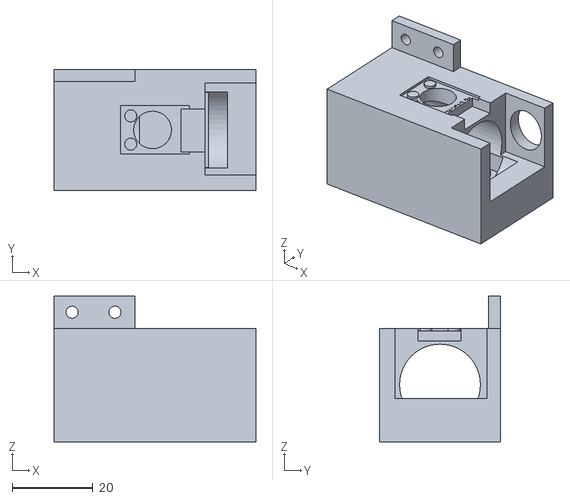
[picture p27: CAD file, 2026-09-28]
hardware/3d/motor-gearbox-mount.stl
50.0 x 30.0 x 36.1

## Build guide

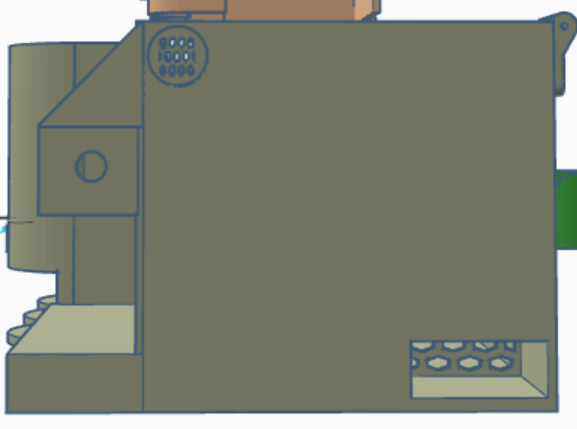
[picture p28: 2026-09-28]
images/cad/assembly-side-elevation.png

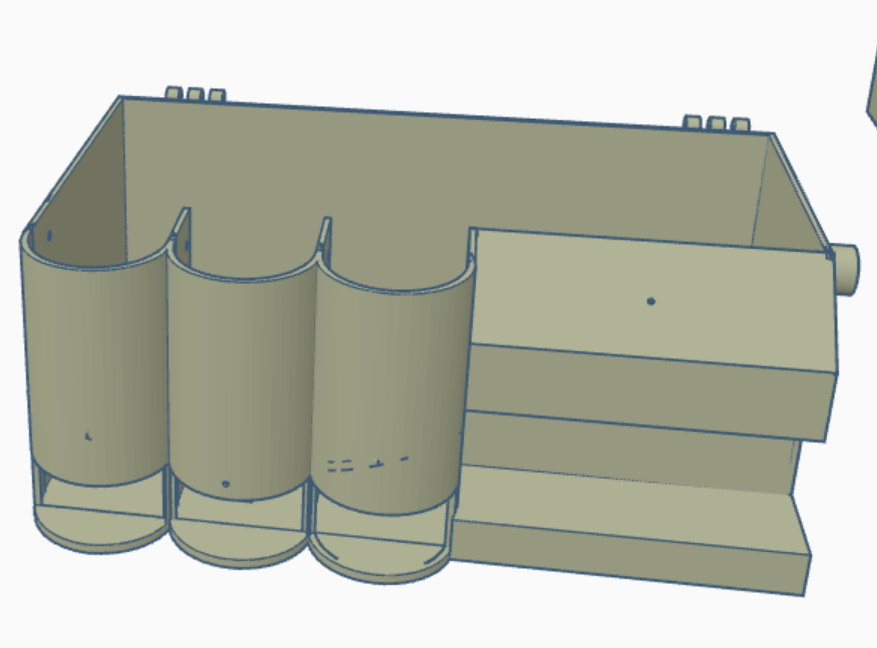
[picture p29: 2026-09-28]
images/cad/assembly-silos-installed.png

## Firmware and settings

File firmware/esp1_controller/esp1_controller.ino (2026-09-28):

/*
  ESP1 FULL CODE (single .ino) — FIXED WiFi disconnects + keep everything intact

  What was fixed (core reasons your web dashboard drops / ESP2 ingest stops):
  - ESP32 WiFi power save can cause idle disconnects / beacon timeouts.
  - When the loop is busy, WiFi background tasks can starve (needs yield).
  - No reconnect logic existed (if WiFi drops, it stays dropped).
  - No debug of disconnect reason (hard to diagnose).

  Fixes added:
  1) Disable WiFi power-save: WiFi.setSleep(false) + esp_wifi_set_ps(WIFI_PS_NONE)
  2) WiFi auto reconnect + periodic reconnect attempts (non-blocking)
  3) WiFi event logging (prints disconnect reason to Serial)
  4) delay(1) yield in loop (helps WiFi stack)
  5) Optional: keep HTTP server responsive (unchanged handlers, but loop yields)

  Kept intact:
  - Your full dashboard HTML/JS (unchanged)
  - Your schedules, sequences, NVS, motors, pumps, emergency, ingest, status JSON

  NOTE:
  - ESP2 sends to ESP1 (ESP1 doesn’t send to ESP2). If ESP1 WiFi drops,
    ESP2 /ingest fails -> looks like "stops sending".
*/

#include <DHT.h>
#include <WiFi.h>
#include <WebServer.h>
#include <time.h>
#include <Preferences.h>
#include "esp_wifi.h"

// ---------------- PINS ----------------
#define M1_IN1 16
#define M1_IN2 17
#define M2_IN1 18
#define M2_IN2 19
#define M3_IN1 21
#define M3_IN2 22
#define STBY1 23
#define STBY2 5

#define PIEZO 34
#define PIEZO_THRESHOLD 400

#define PUMP1_PIN 26
#define PUMP2_PIN 27

#define BUTTON 32
#define EMERGENCY_SWITCH 33
#define BUZZER_PIN 13

// LEDs
#define LED_SEQ_START 14
#define LED_SEQ_DONE 12
#define LED_PUMP_START 25
#define LED_PUMP_DONE 2

#define DHTPIN 4
#define DHTTYPE DHT22
DHT dht(DHTPIN, DHTTYPE);

// ---------------- NVS ----------------
Preferences prefs;
static const char* PREF_NS = "appcfg";

// ---------------- MOTOR STRUCT ----------------
struct Motor {
  int in1;
  int in2;
  bool active;
};
Motor motors[3];

// ---------------- LIMITS ----------------
static const int MAX_MOTORS = 3;
static const int MAX_PUMPS = 2;

// ---------------- DEFAULT ACTIVE SETTINGS ----------------
int motorSequence[MAX_MOTORS] = {0, 1, 2};
int pumpSequence[MAX_PUMPS]   = {1, 0};
int motorSeqLen = 3;
int pumpSeqLen  = 2;

int pillTarget[MAX_MOTORS]    = {5, 5, 5};
int pillRemaining[MAX_MOTORS] = {5, 5, 5};

// Pump levels: 0 short, 1 medium, 2 long
unsigned long pumpRunTime[MAX_PUMPS][3] = {
  {1000, 2000, 5000},   // Pump0
  {1500, 2500, 4500}    // Pump1
};
int pumpLevelSelection[MAX_PUMPS] = {1, 0};

// ---------------- SCHEDULES ----------------
enum PartId { PART_MORNING = 0, PART_DAY = 1, PART_NIGHT = 2 };

struct PartConfig {
  bool enabled;
  int startMin; // [0..1439]
  int endMin;   // [0..1439]

  int motSeq[MAX_MOTORS];
  int motLen;

  int pumSeq[MAX_PUMPS];
  int pumLen;

  int pumpLevel[MAX_PUMPS]; // per pump 0..2
};
PartConfig parts[3];

// runtime picked at button press
int runtimeMotSeq[MAX_MOTORS];
int runtimeMotLen = 0;
int runtimePumSeq[MAX_PUMPS];
int runtimePumLen = 0;
int runtimePumpLevel[MAX_PUMPS] = {0, 0};
String runtimeSource = "DEFAULT";

// ---------------- STATE MACHINE ----------------
enum SequenceState { IDLE, RUN_MOTOR, WAIT_AFTER_PILL, RUN_PUMP };
SequenceState seqState = IDLE;

int motorIndex = 0;
int pumpIndex = 0;
bool pillDetected = false;

unsigned long pillDelayStart = 0;
const unsigned long pillDelay = 2000;
unsigned long pumpStartMillis = 0;
bool lastButtonState = HIGH;

// LED timers
unsigned long seqDoneLEDTimer = 0;
unsigned long pumpDoneLEDTimer = 0;
const unsigned long LED_TIMEOUT = 10000;

// Emergency
unsigned long previousSirenMillis = 0;
bool sirenState = false;

// ---------------- WIFI & Web ----------------
const char* ssid     = "YOUR_WIFI_SSID";
const char* password = "YOUR_WIFI_PASSWORD";
WebServer server(80);
String uiMessage = "Ready";

// WiFi stability
unsigned long lastWiFiCheckMs = 0;
const unsigned long WIFI_CHECK_MS = 3000;
unsigned long lastWiFiOkMs = 0;

// ---------------- NTP TIME ----------------
const long gmtOffset_sec = 21600;
const int daylightOffset_sec = 0;
const char* ntpServer = "pool.ntp.org";

// ---------------- ESP2 SENSOR CACHE ----------------
struct RemoteSensors {
  bool ok = false;
  unsigned long lastMs = 0;
  int bpm = 0;
  float bodyTempC = 0;
  float irTempC = 0;
  int waterRaw = 0;
} remote;

// Water raw calibration (adjust later if needed)
int waterMinRaw = 0;
int waterMaxRaw = 4095;

// ---------------- TIME HELPERS ----------------
bool timeReady() {
  time_t now = time(nullptr);
  return now > 1700000000;
}
bool getTimeInfo(struct tm &timeinfo) { return getLocalTime(&timeinfo, 100); }
int minutesOfDayNow() {
  struct tm t;
  if (!getTimeInfo(t)) return -1;
  return t.tm_hour * 60 + t.tm_min;
}
String nowHHMM() {
  struct tm t;
  if (!getTimeInfo(t)) return "--:--";
  char buf[6];
  snprintf(buf, sizeof(buf), "%02d:%02d", t.tm_hour, t.tm_min);
  return String(buf);
}
bool windowActive(int nowMin, int startMin, int endMin) {
  if (nowMin < 0) return false;
  if (startMin == endMin) return true;
  if (startMin < endMin) return (nowMin >= startMin && nowMin < endMin);
  return (nowMin >= startMin) || (nowMin < endMin);
}
const char* partName(PartId id) {
  switch (id) {
    case PART_MORNING: return "MORNING";
    case PART_DAY: return "DAY";
    case PART_NIGHT: return "NIGHT";
    default: return "UNKNOWN";
  }
}
PartId activePart() {
  if (!timeReady()) return (PartId)-1;
  int nowMin = minutesOfDayNow();
  for (int i = 0; i < 3; i++) {
    if (!parts[i].enabled) continue;
    if (windowActive(nowMin, parts[i].startMin, parts[i].endMin)) return (PartId)i;
  }
  return (PartId)-1;
}

// ---------------- UTIL ----------------
String arrayToCsvLen(const int* arr, int len) {
  String s;
  for (int i = 0; i < len; i++) { if (i) s += ","; s += String(arr[i]); }
  return s;
}
String jsonEscape(const String& in) {
  String out; out.reserve(in.length() + 8);
  for (size_t i = 0; i < in.length(); i++) {
    char c = in[i];
    if (c == '\\') out += "\\\\";
    else if (c == '"') out += "\\\"";
    else if (c == '\n') out += "\\n";
    else if (c == '\r') out += "\\r";
    else out += c;
  }
  return out;
}
bool parseCsvToArrayVarLen(const String& csv, int* out, int maxLen, int& outLen, int minVal, int maxVal) {
  String s = csv; s.trim();
  if (s.length() == 0) return false;
  int count = 0, start = 0;
  for (int i = 0; i <= (int)s.length(); i++) {
    if (i == (int)s.length() || s[i] == ',') {
      String token = s.substring(start, i); token.trim();
      if (token.length() == 0) return false;
      if (count >= maxLen) return false;
      int v = token.toInt();
      if (!(token == "0" || v != 0)) return false;
      if (v < minVal || v > maxVal) return false;
      out[count++] = v;
      start = i + 1;
    }
  }
  if (count <= 0) return false;
  outLen = count;
  return true;
}
bool hasDuplicates(const int* arr, int len) {
  for (int i = 0; i < len; i++) for (int j = i + 1; j < len; j++) if (arr[i] == arr[j]) return true;
  return false;
}
const char* seqStateToString(SequenceState st) {
  switch (st) {
    case IDLE: return "IDLE";
    case RUN_MOTOR: return "RUN_MOTOR";
    case WAIT_AFTER_PILL: return "WAIT_AFTER_PILL";
    case RUN_PUMP: return "RUN_PUMP";
    default: return "UNKNOWN";
  }
}

int clampi(int v, int lo, int hi) { return v < lo ? lo : (v > hi ? hi : v); }

int waterPercent() {
  if (!remote.ok) return 0;
  int mn = waterMinRaw, mx = waterMaxRaw;
  if (mx <= mn) return 0;
  int r = clampi(remote.waterRaw, mn, mx);
  int pct = (int)((long)(r - mn) * 100L / (long)(mx - mn));
  return clampi(pct, 0, 100);
}

// ---------------- DEFAULTS ----------------
void initPartsDefaults() {
  parts[PART_MORNING].enabled = false;
  parts[PART_MORNING].startMin = 6 * 60;
  parts[PART_MORNING].endMin   = 10 * 60;
  parts[PART_MORNING].motLen = 3;
  parts[PART_MORNING].motSeq[0]=0; parts[PART_MORNING].motSeq[1]=1; parts[PART_MORNING].motSeq[2]=2;
  parts[PART_MORNING].pumLen = 2;
  parts[PART_MORNING].pumSeq[0]=1; parts[PART_MORNING].pumSeq[1]=0;
  parts[PART_MORNING].pumpLevel[0]=1; parts[PART_MORNING].pumpLevel[1]=0;

  parts[PART_DAY].enabled = false;
  parts[PART_DAY].startMin = 10 * 60;
  parts[PART_DAY].endMin   = 18 * 60;
  parts[PART_DAY].motLen = 2;
  parts[PART_DAY].motSeq[0]=0; parts[PART_DAY].motSeq[1]=2;
  parts[PART_DAY].pumLen = 1;
  parts[PART_DAY].pumSeq[0]=1;
  parts[PART_DAY].pumpLevel[0]=0; parts[PART_DAY].pumpLevel[1]=1;

  parts[PART_NIGHT].enabled = false;
  parts[PART_NIGHT].startMin = 18 * 60;
  parts[PART_NIGHT].endMin   = 6 * 60;
  parts[PART_NIGHT].motLen = 1;
  parts[PART_NIGHT].motSeq[0]=1;
  parts[PART_NIGHT].pumLen = 1;
  parts[PART_NIGHT].pumSeq[0]=0;
  parts[PART_NIGHT].pumpLevel[0]=2; parts[PART_NIGHT].pumpLevel[1]=2;
}

// ---------------- NVS ----------------
void nvsSaveDefaults() {
  prefs.begin(PREF_NS, false);

  prefs.putInt("motLen", motorSeqLen);
  prefs.putInt("mot0", motorSequence[0]);
  prefs.putInt("mot1", motorSequence[1]);
  prefs.putInt("mot2", motorSequence[2]);

  prefs.putInt("pumLen", pumpSeqLen);
  prefs.putInt("pum0", pumpSequence[0]);
  prefs.putInt("pum1", pumpSequence[1]);

  prefs.putInt("pl0", pumpLevelSelection[0]);
  prefs.putInt("pl1", pumpLevelSelection[1]);

  prefs.putInt("t0", pillTarget[0]);
  prefs.putInt("t1", pillTarget[1]);
  prefs.putInt("t2", pillTarget[2]);
  prefs.putInt("r0", pillRemaining[0]);
  prefs.putInt("r1", pillRemaining[1]);
  prefs.putInt("r2", pillRemaining[2]);

  prefs.putBool("hasAll", true);
  prefs.end();
}

void nvsLoadDefaults() {
  prefs.begin(PREF_NS, true);
  bool has = prefs.getBool("hasAll", false);
  if (has) {
    motorSeqLen = prefs.getInt("motLen", motorSeqLen);
    if (motorSeqLen < 1) motorSeqLen = 1;
    if (motorSeqLen > MAX_MOTORS) motorSeqLen = MAX_MOTORS;
    motorSequence[0] = prefs.getInt("mot0", motorSequence[0]);
    motorSequence[1] = prefs.getInt("mot1", motorSequence[1]);
    motorSequence[2] = prefs.getInt("mot2", motorSequence[2]);

    pumpSeqLen = prefs.getInt("pumLen", pumpSeqLen);
    if (pumpSeqLen < 1) pumpSeqLen = 1;
    if (pumpSeqLen > MAX_PUMPS) pumpSeqLen = MAX_PUMPS;
    pumpSequence[0] = prefs.getInt("pum0", pumpSequence[0]);
    pumpSequence[1] = prefs.getInt("pum1", pumpSequence[1]);

    pumpLevelSelection[0] = prefs.getInt("pl0", pumpLevelSelection[0]);
    pumpLevelSelection[1] = prefs.getInt("pl1", pumpLevelSelection[1]);

    pillTarget[0] = prefs.getInt("t0", pillTarget[0]);
    pillTarget[1] = prefs.getInt("t1", pillTarget[1]);
    pillTarget[2] = prefs.getInt("t2", pillTarget[2]);
    pillRemaining[0] = prefs.getInt("r0", pillRemaining[0]);
    pillRemaining[1] = prefs.getInt("r1", pillRemaining[1]);
    pillRemaining[2] = prefs.getInt("r2", pillRemaining[2]);
  }
  prefs.end();
}

void nvsSaveParts() {
  prefs.begin(PREF_NS, false);
  prefs.putBool("hasParts", true);

  for (int i = 0; i < 3; i++) {
    String p = "p" + String(i) + "_";
    prefs.putBool((p + "en").c_str(), parts[i].enabled);
    prefs.putInt((p + "s").c_str(), parts[i].startMin);
    prefs.putInt((p + "e").c_str(), parts[i].endMin);

    prefs.putInt((p + "ml").c_str(), parts[i].motLen);
    for (int k = 0; k < parts[i].motLen; k++) prefs.putInt((p + "m" + String(k)).c_str(), parts[i].motSeq[k]);

    prefs.putInt((p + "pl").c_str(), parts[i].pumLen);
    for (int k = 0; k < parts[i].pumLen; k++) prefs.putInt((p + "pu" + String(k)).c_str(), parts[i].pumSeq[k]);

    prefs.putInt((p + "l0").c_str(), parts[i].pumpLevel[0]);
    prefs.putInt((p + "l1").c_str(), parts[i].pumpLevel[1]);
  }
  prefs.end();
}

void nvsLoadParts() {
  prefs.begin(PREF_NS, true);
  bool has = prefs.getBool("hasParts", false);
  if (has) {
    for (int i = 0; i < 3; i++) {
      String p = "p" + String(i) + "_";
      parts[i].enabled = prefs.getBool((p + "en").c_str(), parts[i].enabled);
      parts[i].startMin = prefs.getInt((p + "s").c_str(), parts[i].startMin);
      parts[i].endMin   = prefs.getInt((p + "e").c_str(), parts[i].endMin);

      parts[i].motLen = prefs.getInt((p + "ml").c_str(), parts[i].motLen);
      if (parts[i].motLen < 1) parts[i].motLen = 1;
      if (parts[i].motLen > MAX_MOTORS) parts[i].motLen = MAX_MOTORS;
      for (int k = 0; k < parts[i].motLen; k++) parts[i].motSeq[k] = prefs.getInt((p + "m" + String(k)).c_str(), parts[i].motSeq[k]);

      parts[i].pumLen = prefs.getInt((p + "pl").c_str(), parts[i].pumLen);
      if (parts[i].pumLen < 1) parts[i].pumLen = 1;
      if (parts[i].pumLen > MAX_PUMPS) parts[i].pumLen = MAX_PUMPS;
      for (int k = 0; k < parts[i].pumLen; k++) parts[i].pumSeq[k] = prefs.getInt((p + "pu" + String(k)).c_str(), parts[i].pumSeq[k]);

      parts[i].pumpLevel[0] = prefs.getInt((p + "l0").c_str(), parts[i].pumpLevel[0]);
      parts[i].pumpLevel[1] = prefs.getInt((p + "l1").c_str(), parts[i].pumpLevel[1]);
    }
  }
  prefs.end();
}

// ---------------- Runtime picking ----------------
void loadRuntimeFromDefault() {
  runtimeMotLen = motorSeqLen;
  runtimePumLen = pumpSeqLen;
  for (int i = 0; i < runtimeMotLen; i++) runtimeMotSeq[i] = motorSequence[i];
  for (int i = 0; i < runtimePumLen; i++) runtimePumSeq[i] = pumpSequence[i];
  runtimePumpLevel[0] = pumpLevelSelection[0];
  runtimePumpLevel[1] = pumpLevelSelection[1];
  runtimeSource = "DEFAULT";
}
void loadRuntimeFromPart(PartId id) {
  PartConfig &p = parts[(int)id];
  runtimeMotLen = p.motLen;
  runtimePumLen = p.pumLen;
  for (int i = 0; i < runtimeMotLen; i++) runtimeMotSeq[i] = p.motSeq[i];
  for (int i = 0; i < runtimePumLen; i++) runtimePumSeq[i] = p.pumSeq[i];
  runtimePumpLevel[0] = p.pumpLevel[0];
  runtimePumpLevel[1] = p.pumpLevel[1];
  runtimeSource = partName(id);
}
void pickRuntimeForButton() {
  loadRuntimeFromDefault();
  if (!timeReady()) return;
  PartId ap = activePart();
  if ((int)ap >= 0) loadRuntimeFromPart(ap);
}

// ---------------- WiFi stability helpers ----------------
void setupWiFiEvents() {
  WiFi.onEvent([](WiFiEvent_t event, WiFiEventInfo_t info) {
    if (event == ARDUINO_EVENT_WIFI_STA_DISCONNECTED) {
      Serial.printf("[WiFi] DISCONNECTED reason=%d\n", info.wifi_sta_disconnected.reason);
    } else if (event == ARDUINO_EVENT_WIFI_STA_CONNECTED) {
      Serial.println("[WiFi] Connected to AP");
    } else if (event == ARDUINO_EVENT_WIFI_STA_GOT_IP) {
      Serial.print("[WiFi] GOT IP: ");
      Serial.println(WiFi.localIP());
    }
  });
}

void ensureWiFiConnectedNonBlocking(unsigned long nowMs) {
  if (nowMs - lastWiFiCheckMs < WIFI_CHECK_MS) return;
  lastWiFiCheckMs = nowMs;

  if (WiFi.status() == WL_CONNECTED) {
    lastWiFiOkMs = nowMs;
    return;
  }

  Serial.println("[WiFi] Reconnecting...");
  WiFi.disconnect(false, false);
  WiFi.begin(ssid, password);
}
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
void loop() {
  server.handleClient();

  unsigned long currentMillis = millis();

  // WiFi keep-alive (does NOT touch seqState)
  ensureWiFiConnectedNonBlocking(currentMillis);

  // Print RSSI periodically (helpful for diagnosing)
  static unsigned long lastRssiMs = 0;
  if (currentMillis - lastRssiMs > 5000) {
    lastRssiMs = currentMillis;
    Serial.printf("[WiFi] status=%d RSSI=%d dBm IP=%s\n",
                  (int)WiFi.status(), WiFi.RSSI(), WiFi.localIP().toString().c_str());
  }

  handleEmergency(currentMillis);

  // Button start (uses schedule at press time)
  bool currentButtonState = digitalRead(BUTTON);
  if (lastButtonState == HIGH && currentButtonState == LOW && seqState == IDLE) {
    pickRuntimeForButton();

    motorSeqLen = runtimeMotLen;
    pumpSeqLen = runtimePumLen;
    for (int i=0;i<motorSeqLen;i++) motorSequence[i]=runtimeMotSeq[i];
    for (int i=0;i<pumpSeqLen;i++)  pumpSequence[i]=runtimePumSeq[i];
    pumpLevelSelection[0]=runtimePumpLevel[0];
    pumpLevelSelection[1]=runtimePumpLevel[1];

    motorIndex = 0;
    pumpIndex = 0;

    while (motorIndex < motorSeqLen && pillRemaining[motorSequence[motorIndex]] <= 0) motorIndex++;

    if (motorIndex < motorSeqLen) {
      motors[motorSequence[motorIndex]].active = true;
      seqState = RUN_MOTOR;
      digitalWrite(LED_SEQ_START, HIGH);
      uiMessage = "Started via Button (" + runtimeSource + ").";
    } else {
      uiMessage = "All motors have 0 remaining pills.";
    }
  }
  lastButtonState = currentButtonState;

  switch (seqState) {
    case IDLE: break;

    case RUN_MOTOR:
      runMotorUntilPill(motorSequence[motorIndex], currentMillis);
      break;

    case WAIT_AFTER_PILL:
      if (currentMillis - pillDelayStart >= pillDelay) {
        motorIndex++;
        while (motorIndex < motorSeqLen && pillRemaining[motorSequence[motorIndex]] <= 0) motorIndex++;
        if (motorIndex < motorSeqLen) {
          motors[motorSequence[motorIndex]].active = true;
          seqState = RUN_MOTOR;
        } else {
          pumpStartMillis = currentMillis;
          pumpIndex = 0;
          seqState = RUN_PUMP;
          digitalWrite(LED_SEQ_START, LOW);
          digitalWrite(LED_SEQ_DONE, HIGH);
          seqDoneLEDTimer = currentMillis;
          uiMessage = "Motors done. Starting pumps.";
        }
      }
      break;

    case RUN_PUMP:
      runPumpSequence(currentMillis);
      break;
  }

  if (seqDoneLEDTimer > 0 && currentMillis - seqDoneLEDTimer >= LED_TIMEOUT) {
    digitalWrite(LED_SEQ_DONE, LOW);
    seqDoneLEDTimer = 0;
  }
  if (pumpDoneLEDTimer > 0 && currentMillis - pumpDoneLEDTimer >= LED_TIMEOUT) {
    digitalWrite(LED_PUMP_DONE, LOW);
    pumpDoneLEDTimer = 0;
  }

  // IMPORTANT: yield for WiFi/background tasks (stability)
  delay(1);
}

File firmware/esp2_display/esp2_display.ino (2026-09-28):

/*
  SAME UI STYLE as your last sketch, but with requested fixes:

  1) MUCH LESS FLICKER:
     - Full background + cards are drawn only every FULL_REDRAW_MS
     - Animations + numbers update via partial redraw (small rectangles) every ANIM_MS
     This keeps the same look, but removes "whole screen flashing".

  2) Motor/Pump dots moved DOWN and made SMALLER so they don't touch Pills M2 bar.

  3) Water level shows 0% issue:
     - We keep sending raw to ESP1 (unchanged)
     - On TFT we compute water% from ESP2 raw always.
     - Added smoothing to avoid jumping and reading noise.

  4) Water section size reduced slightly to fit nicely.

  Configure:
   - FULL_REDRAW_MS: 4000 (you can increase more)
   - ANIM_MS: 220

  NOTE:
   - Keeps W=480,H=320 assumption as you are using landscape.
*/

#include <WiFi.h>
#include <HTTPClient.h>
#include <ArduinoJson.h>

#include <Wire.h>
#include <MAX30105.h>
#include "spo2_algorithm.h"

#include <TFT_eSPI.h>
#include <SPI.h>

// ================= WiFi / ESP1 =================
const char* ssid     = "YOUR_WIFI_SSID";
const char* password = "YOUR_WIFI_PASSWORD";
const char* ESP1_IP = "192.168.0.101";   // <-- CHANGE

static const uint32_t POLL_STATUS_MS = 1000;
static const uint32_t SEND_INGEST_MS = 1500;

// UI refresh
static const uint32_t FULL_REDRAW_MS = 4000;  // background/cards redraw
static const uint32_t ANIM_MS = 220;          // partial updates

// ================= TFT =================
TFT_eSPI tft = TFT_eSPI();
static const int W = 480;
static const int H = 320;

// ---------------- Rect ----------------
struct Rect { int x; int y; int w; int h; };

// Color helpers
static inline uint16_t rgb565(uint8_t r, uint8_t g, uint8_t b) {
  return ((r & 0xF8) << 8) | ((g & 0xFC) << 3) | (b >> 3);
}

// Theme colors
static const uint16_t C_CARD     = rgb565(18, 24, 60);
static const uint16_t C_CARD2    = rgb565(16, 20, 52);
static const uint16_t C_LINE     = rgb565(55, 70, 120);
static const uint16_t C_TEXT     = 0xFFFF;
static const uint16_t C_MUTED    = rgb565(150, 165, 210);

static const uint16_t C_BLUE     = rgb565(90, 140, 255);
static const uint16_t C_CYAN     = rgb565(55, 225, 255);
static const uint16_t C_GREEN    = rgb565(35, 209, 122);
static const uint16_t C_YELLOW   = rgb565(255, 180, 32);
static const uint16_t C_ORANGE   = rgb565(255, 120, 50);
static const uint16_t C_RED      = rgb565(255, 77, 77);
static const uint16_t C_PURPLE   = rgb565(180, 90, 255);
static const uint16_t C_PINK     = rgb565(255, 90, 170);
static const uint16_t C_WARN     = C_YELLOW;

// ================= ESP2 Sensors =================
MAX30105 particleSensor;

#define BUFFER_SIZE 100
uint32_t irBuffer[BUFFER_SIZE];
uint32_t redBuffer[BUFFER_SIZE];

#define IR_BASE_SAMPLES 50
#define IR_THRESHOLD 8000
uint32_t irBaseline = 0;

#define BPM_MIN 55
#define BPM_MAX 110
#define BPM_SAMPLES 20

int32_t spo2;
int8_t validSPO2;
int32_t heartRate;
int8_t validHeartRate;

// Temp sensor (your custom I2C)
constexpr uint8_t I2C_ADDRESS = 0x7F;
constexpr uint8_t CMD_REGISTER = 0x30;
constexpr uint8_t DATA_REGISTER_BASE = 0x10;
constexpr uint8_t POWER_ON_CMD = 0x08;
constexpr float TEMPERATURE_SCALE = 16384.0;

// Calibrate to realistic body temp
static const float BODY_TEMP_OFFSET_C = 1.5f;
static const float BODY_TEMP_MIN_C = 34.0f;
static const float BODY_TEMP_MAX_C = 41.0f;
float cToF(float c) { return c * 9.0f / 5.0f + 32.0f; }

// Water ADC
static const int WATER_ADC_PIN = 35;
static const int WATER_EMPTY_RAW = 800;
static const int WATER_FULL_RAW  = 3200;

int clampi(int v, int lo, int hi) { return v < lo ? lo : (v > hi ? hi : v); }

int waterPercentFromRaw(int raw) {
  int mn = WATER_EMPTY_RAW;
  int mx = WATER_FULL_RAW;
  if (mx <= mn) return 0;
  raw = clampi(raw, mn, mx);
  long pct = (long)(raw - mn) * 100L / (long)(mx - mn);
  return clampi((int)pct, 0, 100);
}

// simple smoothing for water %
int smoothPct(int prev, int now) {
  // 70% previous + 30% new
  return (prev * 7 + now * 3) / 10;
}

bool writeCommand(uint8_t command) {
  Wire.beginTransmission(I2C_ADDRESS);
  Wire.write(CMD_REGISTER);
  Wire.write(command);
  return (Wire.endTransmission() == 0);
}

int32_t readTemperatureDataRaw() {
  uint8_t buffer[3] = {0};
  for (int i = 0; i < 3; i++) {
    Wire.beginTransmission(I2C_ADDRESS);
    Wire.write(DATA_REGISTER_BASE + i);
    if (Wire.endTransmission() != 0) return -1;
    Wire.requestFrom(I2C_ADDRESS, 1);
    if (Wire.available()) buffer[i] = Wire.read();
    else return -1;
  }

  int32_t result = (static_cast<int32_t>(buffer[0]) << 16) |
                   (static_cast<int32_t>(buffer[1]) << 8) |
                   buffer[2];

  if (result & 0x00800000) result |= 0xFF000000;
  return result;
}

float readTemperatureC() {
  if (!writeCommand(POWER_ON_CMD)) return NAN;
  delay(50);
  int32_t raw = readTemperatureDataRaw();
  if (raw == -1) return NAN;
  return static_cast<float>(raw) / TEMPERATURE_SCALE;
}

void calibrateIR() {
  uint64_t sum = 0;
  for (int i = 0; i < IR_BASE_SAMPLES; i++) {
    while (!particleSensor.available()) particleSensor.check();
    sum += particleSensor.getIR();
    particleSensor.nextSample();
    delay(20);
  }
  irBaseline = sum / IR_BASE_SAMPLES;
}

bool computeAvgBPM(int &avgBPM, bool &spo2ValidFound, int &spo2Out) {
  uint64_t irSum = 0;
  for (int i = 0; i < BUFFER_SIZE; i++) {
    while (!particleSensor.available()) particleSensor.check();
    irBuffer[i] = particleSensor.getIR();
    redBuffer[i] = particleSensor.getRed();
    irSum += irBuffer[i];
    particleSensor.nextSample();
  }

  bool fingerPresent = (irSum / BUFFER_SIZE) > (irBaseline + IR_THRESHOLD);
  if (!fingerPresent) return false;

  int bpmSum = 0;
  spo2ValidFound = false;

  for (int i = 0; i < BPM_SAMPLES; i++) {
    maxim_heart_rate_and_oxygen_saturation(
      irBuffer, BUFFER_SIZE, redBuffer,
      &spo2, &validSPO2, &heartRate, &validHeartRate
    );

    if (validSPO2 && spo2 >= 90 && spo2 <= 100) spo2ValidFound = true;

    int bpm = (validHeartRate && heartRate >= BPM_MIN && heartRate <= BPM_MAX)
              ? heartRate
              : random(BPM_MIN + 5, BPM_MAX - 5);

    bpmSum += bpm;
    delay(300);
  }

  avgBPM = bpmSum / BPM_SAMPLES;
  spo2Out = (spo2ValidFound ? spo2 : 0);
  return true;
}

// ================= Models =================
struct Esp1Status {
  bool ok = false;
  String nowHHMM;
  String seqState;
  String activePart;

  float dhtTempC = 0;
  float dhtHum = 0;

  int pillTarget[3] = {0,0,0};
  int pillRemaining[3] = {0,0,0};

  bool motorRunning[3] = {false,false,false};
  bool pumpRunning[2] = {false,false};
} esp1;

struct Esp2Sensors {
  int bpm = 0;
  bool finger = false;
  float bodyTempC = 0;
  int waterRaw = 0;
  int waterPct = 0;       // smoothed %
} esp2;

// ================= HTTP =================
String urlBase(const char* path) { return String("http://") + ESP1_IP + String(path); }
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
